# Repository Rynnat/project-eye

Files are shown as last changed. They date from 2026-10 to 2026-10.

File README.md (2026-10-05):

# Project Eye

An animatronic eye mechanism: two eyes that look left/right and up/down, with upper and lower eyelids that blink. Three SG90 micro servos, an Arduino Uno, 3D-printed PLA parts and M3/M4 screws with nuts. Built in a few days as the first module of **Epic Project**, a personal series of human-augmentation builds.

## Built and running

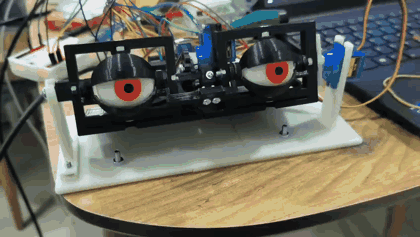
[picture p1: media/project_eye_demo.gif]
Project Eye v5 running on real hardware: eyes look left and right, eyelids move


*v5 on the bench: yaw and eyelids moving (real hardware, 10 s clip).*

## Design

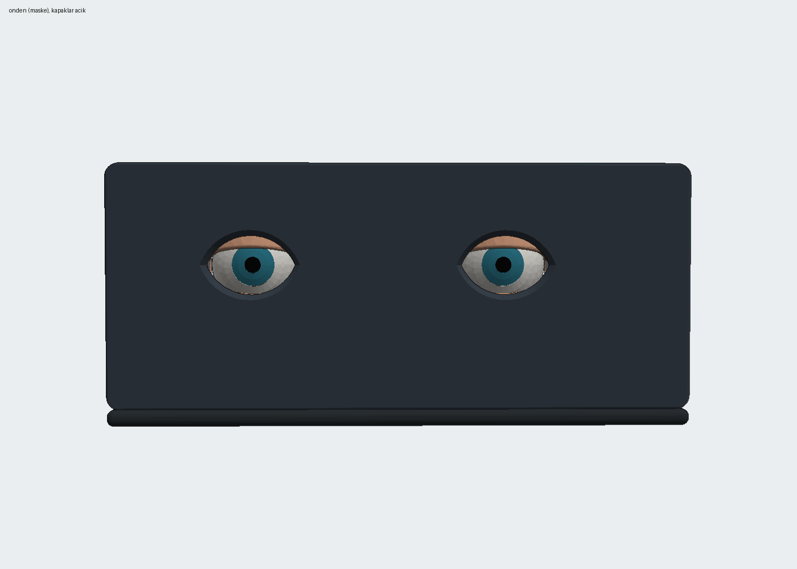
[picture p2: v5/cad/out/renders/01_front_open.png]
Project Eye v5, front view with eyelids open


| Eyelids closed | Three-quarter view | Eyelid drive |
|---|---|---|
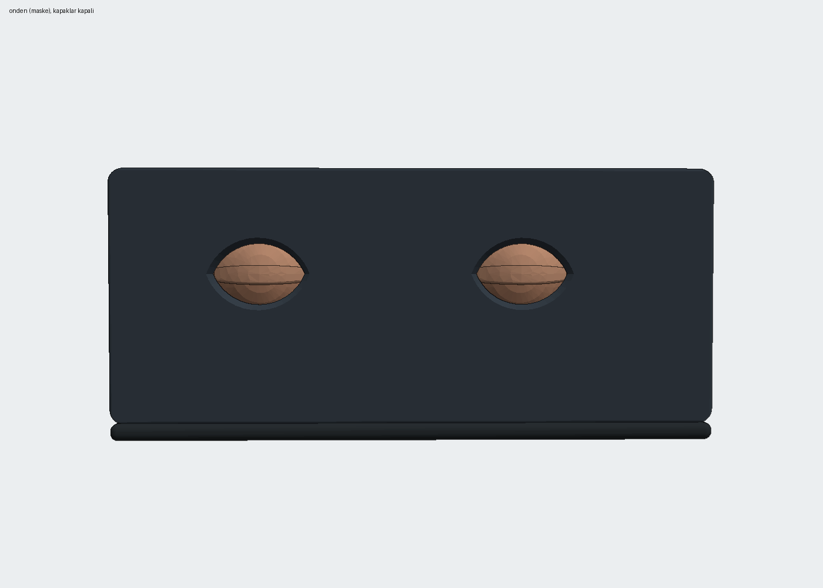
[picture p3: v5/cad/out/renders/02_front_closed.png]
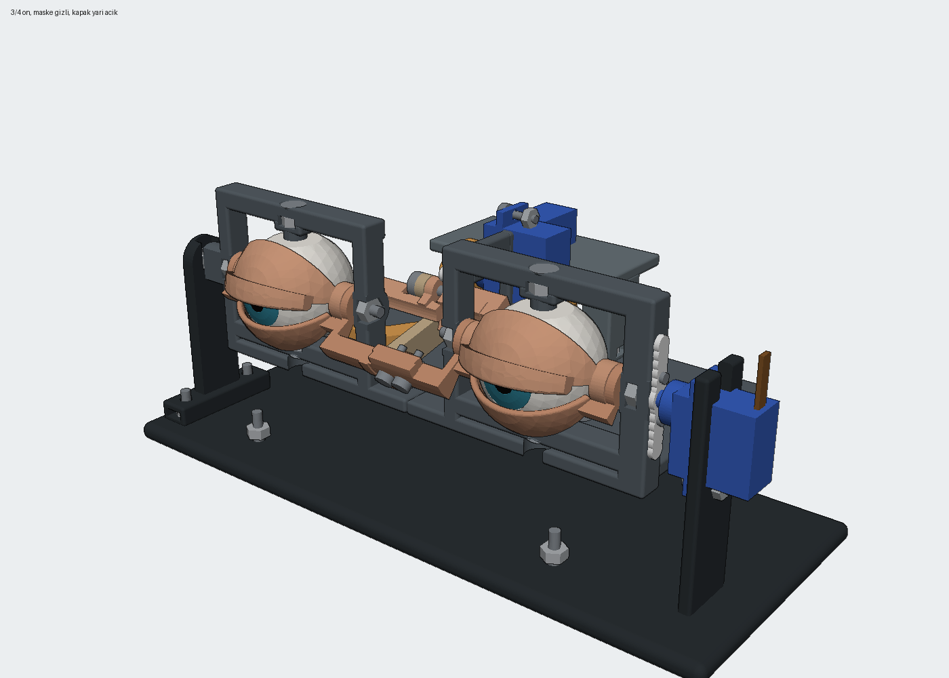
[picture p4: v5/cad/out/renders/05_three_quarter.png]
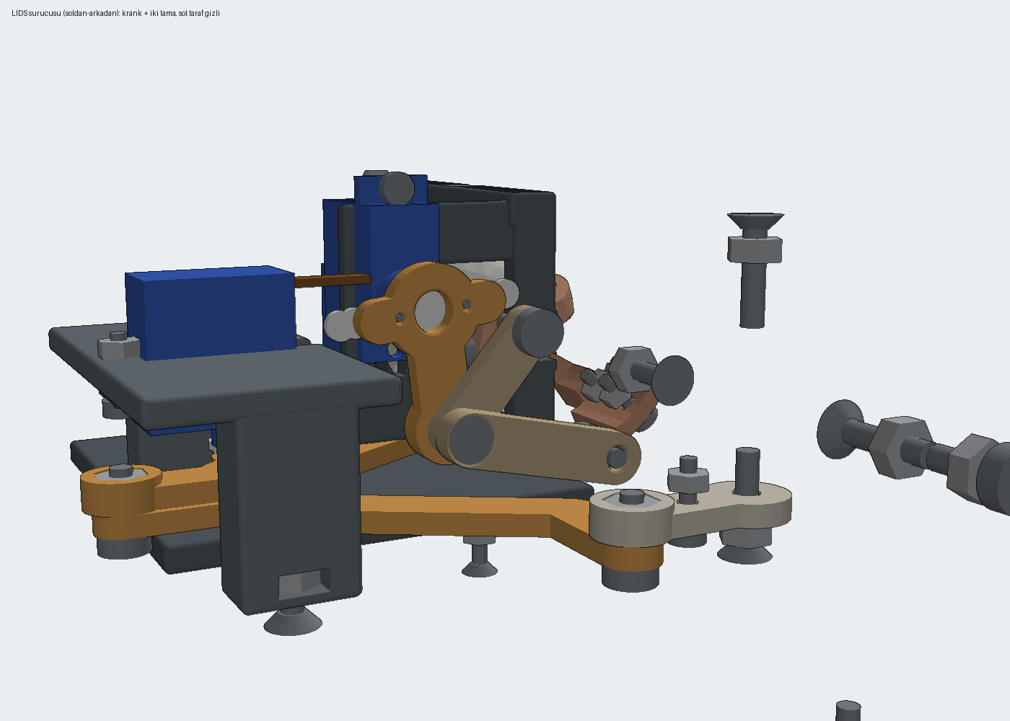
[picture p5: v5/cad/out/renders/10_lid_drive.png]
|  |  |  |

## How it was made

The mechanism was designed as code with AI agents (Claude Code), directed and verified on real hardware by me.

- **CAD as code.** Every part is generated with [CadQuery](https://cadquery.readthedocs.io) from one parameter file (`cad/params.py`). Measured tolerances from printed test pieces go into that file and all parts regenerate.
- **Automatic checks.** After every change the mechanism is swept through 75+ poses (yaw × pitch × eyelid) to check for collisions and minimum clearance (`check.py`). Separate checks catch screws left floating in air (`check_havada.py`) and screws a hand cannot reach in assembly order (`check_montaj.py`). Each of these checks exists because I caught that exact mistake on a printed part.
- **Firmware and control.** Arduino firmware with clamped angle limits taken from the kinematics, a Python serial control library with 45+ unit tests and a simulator, and a button-driven calibration panel.
- **Viewer.** `model.html` is a self-contained 3D viewer of the assembly with live pose sliders.

## Versions

Every version is kept; a revision never edits an older folder.

| Version | What changed |
|---|---|
| v1 | Concept model (viewer only) |
| v2 | Full mechanism: 2 eyes, 4 lids, 6 servos, M2 hardware, ball joints. Software complete, never built |
| v3 | Simplified for a hobby printer: 3 servos, M3/M4 screw pins instead of ball joints |
| v4 | Lower lids on the same servo as the upper lids, front mask, fillets; irises fully covered when closed |
| **v5** | **Built, partly working** (see Status). Captive hex nuts at every joint, separate iris and pupil inserts, base split in two for a 220 mm bed, cable slots on the correct servo end |

## Status

v5 was built as a showcase stand, not as a measured experiment.

- **Yaw (left/right) and eyelids:** work.
- **Pitch (up/down):** the servo moves, but cannot hold the pitch frame under load (the frame also carries the eyelid servo and all four lids). A rubber-band counterbalance on the front of the frame restored free motion, confirming a torque shortfall. A torque check was never part of the design loop; the design notes already flagged it as unverified.
- **Accuracy vs. simulation:** not measured. Since the eyes and lids ride on the pitch frame, their real angles may also differ from the model; hand calibration already found a different yaw range (45–111°) than the model (65–115°).

## v5 at a glance

| | |
|---|---|
| Servos | 3 × SG90: yaw D3, pitch D5, eyelids D6 |
| Board | Arduino Uno, 115200 baud, command `S <yaw> <pitch> <lids>` → `OK` |
| Button | D2 to GND: neutral ↔ idle (LED 13 on in idle) |
| Calibrated range | yaw 45–111° (center 78), eyelids open 80° / closed 115° |
| Parts | 19 STL files, 22 prints, about 250–320 g PLA |
| Hardware | M4×16 countersunk, M4×10 and M3×10 pan head, M3/M4 nuts (see `v5/cad/BOM.md`) |

Folder layout (`v5/`):

```
cad/        params.py, eye_v5.py (geometry), kin.py (kinematics), check*.py, out/ (STL, STEP, GLB, renders)
firmware/   project_eye_v5 (main sketch); notr_yaw_d3, montaj_lids_d3 (assembly helpers)
control/    eye_control.py, sim.py, calibrate.py, kalibrasyon_paneli.py (calibration GUI), face_follow.py, tests/
viewer/     build_viewer.py + template.html → model.html
MONTAJ.md   assembly order (Turkish)
```

## Run it

```powershell
# CAD (Python 3.12 + cadquery)
cd v5/cad
python eye_v5.py; python check.py; python check_havada.py; python check_montaj.py

# Firmware (arduino-cli, board arduino:avr:uno)
arduino-cli compile --fqbn arduino:avr:uno v5/firmware/project_eye_v5
arduino-cli upload  --fqbn arduino:avr:uno -p COM3 v5/firmware/project_eye_v5

# Control (pyserial)
cd v5/control
python -m unittest discover tests
python kalibrasyon_paneli.py --port COM3
```

`face_follow.py` needs mediapipe, OpenCV and a BlazeFace model file; its default path points to my local setup, so pass your own model path.

## Known issues

- **Pitch is weak when looking down.** The parts that tilt with the pitch servo weigh about 225 g, and their center of mass sits about 23 mm behind the pitch axis. Holding it takes about 0.5 kg·cm, roughly 30% of an SG90's stall torque before losses. Fixes: an MG90S (same size, metal gears), a small spring or foam pad under the rear of the frame, and a separate 5 V supply for the servos. Pitch limits (70–110°) are still the model values and have not been calibrated.
- **Servo power.** Running three servos from the Uno's 5 V pin causes brown-out resets on fast moves. Use a separate 5–6 V supply with a shared ground.

## Next

- Face tracking on v5 hardware (`control/face_follow.py`)
- v6: move the center of mass onto the pitch axis

Docs and code comments are partly in Turkish.

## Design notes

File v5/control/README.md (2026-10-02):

# Project Eye v5 — Firmware ve kontrol yazılımı

3 × SG90, Arduino Uno. v3 yazılımının v4 mekaniğine uyarlanmış kopyası (kararlar: `DECISIONS.md`).

> **Durum:** Firmware derleniyor (flash 9538 B %29, RAM 552 B %26); yazılım firmware
> simülatörüne karşı 45 testle doğrulandı. **Gerçek donanımda denenmedi.**

| Kanal | İsim | Pin | Servo aralığı (firmware limiti) |
|---|---|---|---|
| 0 | EYE_YAW | D3 | 65–115 (servo = 90 − yaw) |
| 1 | EYE_PITCH | D5 | 70–110 |
| 2 | LIDS (2 üst + 2 alt kapak) | D6 | 102.29 kapalı … 77.71 açık |

**Kablolama:** servolar **harici 5 V** (≥2 A, 3 A önerilir) kaynaktan; kaynak GND'si **Uno GND'sine
bağlı** (ortak toprak). Harici +5 V'u Uno'ya bağlamayın. Turuncu = sinyal, kırmızı = +5 V,
kahverengi = GND. Servo kolunu takmadan önce servoyu nötre getirin.

## Çalıştırma
```powershell
$py = "C:\Users\LENOVO\epic-project\.venv-ctl\Scripts\python.exe"   # pyserial
cd C:\Users\LENOVO\epic-project\modules\project-eye\v4\control
& $py eye_control.py --sim           # demo (--sim olmadan donanımı arar, yoksa sim)
& $py calibrate.py                   # 1..3 kanal, ok tuşları, c/n/x göz, k/o kapak, s kaydet
& $py -m unittest discover -s tests -v
$env:PYTHONUTF8 = "1"
C:\Users\LENOVO\lunar-tracker\.venv\Scripts\python.exe face_follow.py    # --sim, --port COM5

& "C:\Users\LENOVO\AppData\Local\Programs\Arduino IDE\resources\app\lib\backend\resources\arduino-cli.exe" `
  compile --fqbn arduino:avr:uno ..\firmware\project_eye_v5
```

- Port `auto`: yalnızca açılışta `EYE v5 READY` basan kart kullanılır; Lunar gimbal, v2 ve v3 kartları
  reddedilir. Sabit port için settings.json'da `"serial_port": "COM5"` ya da `EYE_EXCLUDE_PORTS=COM3`.
- `behaviour.lid_follow_pitch` = 0.0: kapaklar pitch'i zaten mekanik olarak izliyor.
- Montajdan sonra: `calibrate.py` ile değerleri bulun; firmware limitlerini yalnızca **daraltın**,
  `IDLE_*` sabitlerini ve `sim.py`'yi yeni settings.json'a çekin (testler farkı yakalar).

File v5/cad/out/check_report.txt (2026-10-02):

PROJECT EYE v5 (v4 + somunlu baglantilar) - MEKANIK KONTROL RAPORU
uretim: check.py | ucgenleme 0.01 mm | kesisim esigi 0.01 mm3 | eklem disi bosluk hedefi 0.4 mm

1) KATI GECERLILIGI
   parca sayisi 96 (basilan 24, farkli basilan STL 19: ['base_L', 'base_R', 'coupler', 'eye', 'eye_lever', 'frame_L', 'frame_R', 'iris', 'lid_lo_L', 'lid_lo_R', 'lid_up_L', 'lid_up_R', 'link_lo', 'link_up', 'mask', 'pivot_bracket', 'pupil', 'yaw_crank', 'yaw_mount'])
   gecersiz kati: yok | tek-kati olmayan basilan: yok | su gecirmez olmayan ag: yok

2) GRUP ICI (birbirine sabit parcalar, notr poz) - kesisim >= esik:
   ! frame_L x scr_ptop_L: 0.012 mm3
   ! frame_L x scr_pbot_L: 0.012 mm3
   ! frame_L x scr_ym_L63: 0.014 mm3
   ! frame_R x scr_ptop_R: 0.012 mm3
   ! frame_R x scr_pbot_R: 0.012 mm3
   ! frame_R x scr_ym_R63: 0.014 mm3
   ! servo_pitch x cable_pitch: 2.340 mm3
   ! servo_pitch x scr_m3_pitch0: 0.434 mm3
   ! servo_pitch x nut_m3_pitch0: 0.776 mm3
   ! servo_yaw x cable_yaw: 2.340 mm3
   ! servo_yaw x scr_m3_yaw0: 0.434 mm3
   ! servo_yaw x nut_m3_yaw0: 0.776 mm3
   ! servo_lid x cable_lid: 2.340 mm3
   ! servo_lid x scr_m3_lid0: 0.434 mm3
   ! servo_lid x nut_m3_lid0: 0.776 mm3
   ! scr_U x lid_up_L: 1.101 mm3
   ! lid_lo_L x lid_lo_R: 2.173 mm3
   ! scr_brk_-4 x base_L: 0.014 mm3
   ! scr_brk_24 x base_L: 0.014 mm3
   ! scr_mask_40 x base_L: 0.014 mm3
   ! scr_mask_160 x base_R: 0.014 mm3
   not: ~0.01-0.02 mm3 = havsa kafa konisi ile yuvasi ayni yuzey (ucgenleme). scr_m3_* x servo_* GERCEK:
        SG90 kulak deligi govdeden ~2.5 mm; M3 kafa (O5.6) govde duvarina biniyor (DECISIONS.md, risk; v3'ten).

3) HAREKET TARAMASI: zorunlu 18 poz (yaw (-25.0, 0.0, 25.0) x pitch (-20.0, 0.0, 20.0) x kapak acik/kapali) + ara tarama 57 poz (yaw 12.5, pitch 10 deg adim, kapak 0/0.5/1)
   ust kapak kenari -4.0 (dudak -10.0) -> +23.0 deg; alt kapak -5.4 -> -34.6 deg
   zorunlu pozlar:  yaw   pitch  kapak  | cakisma | eklem disi min bosluk | en yakin cift
                   -25.0 -20.0  open   |       0 |      0.400 | horn_lid x lid_up_L
                   -25.0   0.0  open   |       0 |      0.400 | coupler x scr_horn_yaw1
                   -25.0  20.0  open   |       0 |      0.400 | coupler x scr_horn_yaw1
                     0.0 -20.0  open   |       0 |      0.400 | horn_lid x lid_up_L
                     0.0   0.0  open   |       0 |      0.400 | horn_lid x lid_up_L
                     0.0  20.0  open   |       0 |      0.400 | horn_lid x lid_up_L
                    25.0 -20.0  open   |       0 |      0.400 | horn_lid x lid_up_L
                    25.0   0.0  open   |       0 |      0.400 | coupler x scr_horn_yaw0
                    25.0  20.0  open   |       0 |      0.400 | coupler x scr_horn_yaw0
                   -25.0 -20.0  closed |       0 |      0.400 | coupler x scr_horn_yaw1
                   -25.0   0.0  closed |       0 |      0.400 | coupler x scr_horn_yaw1
                   -25.0  20.0  closed |       0 |      0.400 | coupler x scr_horn_yaw1
                     0.0 -20.0  closed |       0 |      0.498 | frame_L x lid_up_L
                     0.0   0.0  closed |       0 |      0.498 | frame_L x lid_up_L
                     0.0  20.0  closed |       0 |      0.498 | frame_L x lid_up_L
                    25.0 -20.0  closed |       0 |      0.400 | coupler x scr_horn_yaw0
                    25.0   0.0  closed |       0 |      0.400 | coupler x scr_horn_yaw0
                    25.0  20.0  closed |       0 |      0.400 | coupler x scr_horn_yaw0
   ara tarama: cakisma 0; eklem disi en kucuk bosluk 0.400 mm

   TOPLAM CAKISMA (>= 0.01 mm3): 0
4a) EKLEM DISI CIFTLERDE EN DAR 20 BOSLUK (asil carpisma payi):
     0.400  coupler x scr_horn_yaw0   @ yaw 25.0 pitch 20.0 kapak open
     0.400  coupler x scr_horn_yaw1   @ yaw -25.0 pitch 20.0 kapak open
     0.400  horn_lid x lid_up_L   @ yaw -25.0 pitch -20.0 kapak open
     0.479  eye_lever_R x lid_lo_R   @ yaw 0 pitch -10 kapak 1.0
     0.479  eye_lever_L x lid_lo_L   @ yaw 0.0 pitch 0.0 kapak open
     0.498  frame_L x lid_up_L   @ yaw -25 pitch -10 kapak 0.0
     0.500  scr_ltip_L x frame_L   @ yaw -25 pitch -10 kapak 0.0
     0.500  scr_ltip_R x frame_R   @ yaw -25 pitch -10 kapak 0.0
     0.579  eye_L x lid_up_L   @ yaw 25 pitch -20 kapak 0.5
     0.579  eye_R x lid_up_R   @ yaw 25 pitch -10 kapak 0.5
     0.581  eye_L x lid_lo_L   @ yaw 12.5 pitch -10 kapak 0.0
     0.582  eye_R x lid_lo_R   @ yaw -12.5 pitch -20 kapak 0.0
     0.585  iris_L x lid_up_L   @ yaw -25.0 pitch 0.0 kapak closed
     0.585  iris_R x lid_up_R   @ yaw -25.0 pitch -20.0 kapak closed
     0.585  iris_R x lid_lo_R   @ yaw 25.0 pitch 0.0 kapak closed
     0.585  iris_L x lid_lo_L   @ yaw -25 pitch -10 kapak 0.0
     0.587  pupil_R x lid_lo_R   @ yaw 0 pitch -10 kapak 0.0
     0.587  pupil_L x lid_up_L   @ yaw 0 pitch -10 kapak 0.0
     0.587  pupil_R x lid_up_R   @ yaw 0 pitch -10 kapak 0.0
     0.587  pupil_L x lid_lo_L   @ yaw -12.5 pitch -20 kapak 0.0
4b) EKLEM CIFTLERI (tasarim geregi temas / AXIAL_GAP; en dar 12):
     0.000  scr_ltip_L x coupler
     0.000  scr_ltip_R x coupler
     0.000  servo_pitch x horn_pitch
     0.000  servo_yaw x horn_yaw
     0.000  scr_ctip x coupler
     0.000  servo_lid x horn_lid
     0.000  link_up x scr_U
     0.039  link_lo x scr_A
     0.039  scr_lpin_Ro x lid_up_R
     0.039  scr_lpin_Lo x lid_up_L
     0.039  scr_lpin_Li x lid_up_L
     0.039  scr_lpin_Ri x lid_up_R

5) ET KALINLIGI (isin yontemi; min / %1 / %5, mm) - hedef >= 1.6:
   eye            min  1.60  %1  8.56  %5 14.65  (en ince ~ [-45.3 -11.4 -11.9])
   iris           min  1.97  %1  1.97  %5  1.97  (en ince ~ [-46.2  -2.7  14.1])
   pupil          min  1.65  %1  1.65  %5  1.67  (en ince ~ [-50.1   1.6  17.7])
   eye_lever      min  1.60  %1  1.60  %5  1.60  (en ince ~ [-44.1 -15.3 -21.2])
   frame_L        min  1.25  %1  1.60  %5  4.25  (en ince ~ [-76.    0.    3.5])
   frame_R        min  0.73  %1  1.60  %5  4.05  (en ince ~ [ 18.6  26.5 -29.7])
   yaw_mount      min  0.80  %1  1.60  %5  3.46  (en ince ~ [  0.1   2.6 -77.7])
   yaw_crank      min  1.60  %1  1.60  %5  1.80  (en ince ~ [ -2.7 -15.3 -82.6])
   coupler        min  2.35  %1  2.35  %5  2.36  (en ince ~ [ -2.  -18.1 -80.7])
   link_up        min  1.85  %1  1.85  %5  1.85  (en ince ~ [ -3.9 -10.5 -20.9])
   link_lo        min  2.35  %1  2.35  %5  2.35  (en ince ~ [ -7.6  -8.4 -24.6])
   lid_up_L       min  0.10  %1  1.90  %5  1.99  (en ince ~ [-65.   -1.   11.7])
   lid_lo_L       min  1.60  %1  1.60  %5  1.97  (en ince ~ [ -3.2 -13.1   5.1])
   lid_up_R       min  0.12  %1  1.99  %5  1.99  (en ince ~ [64.9 -0.9 11.7])
   lid_lo_R       min  1.99  %1  1.99  %5  1.99  (en ince ~ [61.3 -6.8 10.5])
   pivot_bracket  min  1.46  %1  1.60  %5  1.60  (en ince ~ [-94.6 -53.9 -19.5])
   base_L         min  2.52  %1  3.00  %5  3.00  (en ince ~ [ -2.4 -54.5 -60.8])
   base_R         min  2.50  %1  3.00  %5  3.00  (en ince ~ [ -9.3 -59.5 -60.9])
   mask           min  1.60  %1  3.00  %5  3.00  (en ince ~ [ 60.8 -52.4   4.1])

6) BASKIDA YATAY DELIKLER (+0.2 mm pay verildi; DECISIONS.md):
   frame_L        ust/alt goz pimi gecisi (Y), 4x kapak mentese gecisi (X), pitch pimi RUN (X, donen)
   frame_R        ust/alt goz pimi gecisi (Y), 4x kapak mentese gecisi (X), 2x pitch kol vidasi (X, servo vidasi), LIDS servo kulagi M3 gecis (X)
   lid_up_L       2x bindirme civatasi (radyal)
   lid_lo_L       2x bindirme civatasi (radyal)
   lid_up_R       2x bindirme civatasi (radyal)
   lid_lo_R       2x bindirme civatasi (radyal)
   pivot_bracket  sol pitch pimi gecisi (X, sabit)
   base_R         2x pitch servo kulagi M3 (X)

7) STL / BASKI YONU KONTROLU (out/stl/*.stl oldugu gibi okunur)
   (1) tek bagli govde  (2) min z = 0, 0.2 mm katmanlarda havada baslayan ada yok  (3) >45 deg sarkma alani
   base_L.stl             govde 1  zmin  0.000  havada ada  0   sarkma  270.7 mm2  tabla 10924.4 mm2  boyut [128.6  89.    6. ]  OK
   base_R.stl             govde 1  zmin  0.000  havada ada  0   sarkma  317.4 mm2  tabla 10909.9 mm2  boyut [128.6  89.   73.5]  OK
   coupler.stl            govde 1  zmin  0.000  havada ada  0   sarkma    0.0 mm2  tabla  1424.6 mm2  boyut [104.   69.    3.5]  OK
   eye.stl                govde 1  zmin  0.000  havada ada  0   sarkma   73.8 mm2  tabla   466.0 mm2  boyut [36.  30.1 29. ]  OK
   eye_lever.stl          govde 1  zmin  0.000  havada ada  0   sarkma    0.0 mm2  tabla   271.2 mm2  boyut [13.  32.4  5. ]  OK
   frame_L.stl            govde 1  zmin  0.000  havada ada  0   sarkma  233.9 mm2  tabla  1498.3 mm2  boyut [88.4 56.5 77.5]  OK
   frame_R.stl            govde 1  zmin  0.000  havada ada  0   sarkma  490.4 mm2  tabla  1578.5 mm2  boyut [83.3 61.5 77.5]  OK
   iris.stl               govde 1  zmin  0.000  havada ada  0   sarkma    0.0 mm2  tabla   201.0 mm2  boyut [16.  16.   3.6]  OK
   lid_lo_L.stl           govde 1  zmin  0.000  havada ada  0   sarkma  412.3 mm2  tabla   112.8 mm2  boyut [26.4 27.6 87.6]  OK
   lid_lo_R.stl           govde 1  zmin  0.000  havada ada  0   sarkma  283.2 mm2  tabla   112.8 mm2  boyut [26.4 20.3 76.4]  OK
   lid_up_L.stl           govde 1  zmin  0.000  havada ada  0   sarkma  433.9 mm2  tabla    98.5 mm2  boyut [39.5 21.1 90.3]  OK
   lid_up_R.stl           govde 1  zmin  0.000  havada ada  0   sarkma  392.7 mm2  tabla    98.5 mm2  boyut [41.  21.1 67.6]  OK
   link_lo.stl            govde 1  zmin  0.000  havada ada  0   sarkma    9.0 mm2  tabla   242.2 mm2  boyut [36.7 15.5  4.5]  OK
   link_up.stl            govde 1  zmin  0.000  havada ada  0   sarkma    0.0 mm2  tabla   182.1 mm2  boyut [19.1 26.1  3.5]  OK
   mask.stl               govde 1  zmin  0.000  havada ada  0   sarkma  367.0 mm2  tabla 18367.7 mm2  boyut [217.5  92.   30.4]  OK
   pivot_bracket.stl      govde 1  zmin  0.000  havada ada  0   sarkma  110.3 mm2  tabla   379.7 mm2  boyut [11. 40. 62.]  OK
   pupil.stl              govde 1  zmin  0.000  havada ada  0   sarkma    0.0 mm2  tabla    28.3 mm2  boyut [6.  6.  1.9]  OK
   yaw_crank.stl          govde 1  zmin  0.000  havada ada  0   sarkma    0.0 mm2  tabla   366.7 mm2  boyut [26.  33.9  5. ]  OK
   yaw_mount.stl          govde 1  zmin  0.000  havada ada  0   sarkma   97.4 mm2  tabla  2063.3 mm2  boyut [69.  35.4 30.4]  OK
   STL SONUC: hepsi OK

8) VIDA SAYILARI (montaj kaydindan):
     8  M3 somun
     8  M3x10 yuvarlak
    20  M4 somun
     6  M4x10 yuvarlak
    15  M4x16 havsa
     3  SG90
     3  SG90 kablo cikisi
     6  SG90 kol vidasi (servo ile gelir)
     3  SG90 kolu (cift)
   M3 toplam 8 (sinir 14) -> OK
8b) VIDA BOYU / SOMUN KONTROLU: vida ucu somunun dis yuzunden en az 1 dis (M3 0.5, M4 0.7) cikmali;
    vidalarin/somunlarin baska parcaya carpmamasi bolum 2-4'teki carpisma taramasinda (vida ve somun katilari dahil).
   scr_lock_L       + nut_lock_L       M3: uc somundan  2.10 mm tasar  OK
   scr_ltip_L       + nut_ltip_L       M4: uc somundan  1.30 mm tasar  OK
   scr_lock_R       + nut_lock_R       M3: uc somundan  2.10 mm tasar  OK
   scr_ltip_R       + nut_ltip_R       M4: uc somundan  1.30 mm tasar  OK
   scr_ptop_L       + nut_ptop_L       M4: uc somundan  9.45 mm tasar  OK
   scr_pbot_L       + nut_pbot_L       M4: uc somundan 10.50 mm tasar  OK
   scr_lpin_Lo      + nut_lpin_Lo      M4: uc somundan  3.30 mm tasar  OK
   scr_lpin_Li      + nut_lpin_Li      M4: uc somundan  3.30 mm tasar  OK
   scr_ptop_R       + nut_ptop_R       M4: uc somundan  9.45 mm tasar  OK
   scr_pbot_R       + nut_pbot_R       M4: uc somundan 10.50 mm tasar  OK
   scr_lpin_Ro      + nut_lpin_Ro      M4: uc somundan  3.30 mm tasar  OK
   scr_lpin_Ri      + nut_lpin_Ri      M4: uc somundan  3.30 mm tasar  OK
   scr_fpivot       + nut_fpivot       M4: uc somundan  5.20 mm tasar  OK
   scr_m3_yaw0      + nut_m3_yaw0      M3: uc somundan  1.10 mm tasar  OK
   scr_ym_L63       + nut_ym_L63       M4: uc somundan  6.90 mm tasar  OK
   scr_ym_R63       + nut_ym_R63       M4: uc somundan  6.90 mm tasar  OK
   scr_ctip         + nut_ctip         M4: uc somundan  1.30 mm tasar  OK
   scr_m3_lid0      + nut_m3_lid0      M3: uc somundan  1.00 mm tasar  OK
   scr_A            + nut_A            M4: uc somundan  2.64 mm tasar  OK
   scr_L            + nut_L            M4: uc somundan  5.20 mm tasar  OK
   scr_lap_up0      + nut_lap_up0      M3: uc somundan  1.60 mm tasar  OK
   scr_lap_lo0      + nut_lap_lo0      M3: uc somundan  2.60 mm tasar  OK
   scr_lap_lo1      + nut_lap_lo1      M3: uc somundan  2.60 mm tasar  OK
   scr_brk_-4       + nut_brk_-4       M4: uc somundan  5.50 mm tasar  OK
   scr_brk_24       + nut_brk_24       M4: uc somundan  5.50 mm tasar  OK
   scr_mask_40      + nut_mask_40      M4: uc somundan  5.50 mm tasar  OK
   scr_mask_160     + nut_mask_160     M4: uc somundan  5.50 mm tasar  OK
   scr_m3_pitch0    + nut_m3_pitch0    M3: uc somundan  1.10 mm tasar  OK
   somunlu baglanti 28, kisa vida: yok
   KILAVUZSUZ (plastige vidalanan) kalan: ['scr_U'] (M4, ust kapak tabi; bkz. DECISIONS) + SG90 kol vidalari (servo ile gelen)

9) SERVO ACILARI (derece) + kapak acilari:
   kapak 0.00: ust + 0.00 deg, alt - 0.00 deg, krank   0.00 deg, LIDS 102.29; lama iletim sapmasi (0 ideal) ust  6.1 alt 31.0 krank-ust 38.9 krank-alt 32.7
   kapak 0.25: ust + 6.75 deg, alt - 7.59 deg, krank  -6.40 deg, LIDS  95.89; lama iletim sapmasi (0 ideal) ust  4.5 alt 23.2 krank-ust 41.4 krank-alt 26.1
   kapak 0.50: ust +13.50 deg, alt -15.29 deg, krank -12.90 deg, LIDS  89.39; lama iletim sapmasi (0 ideal) ust 16.2 alt 15.3 krank-ust 43.0 krank-alt 19.3
   kapak 0.75: ust +20.25 deg, alt -22.66 deg, krank -19.10 deg, LIDS  83.18; lama iletim sapmasi (0 ideal) ust 28.7 alt  7.5 krank-ust 43.4 krank-alt 12.8
   kapak 1.00: ust +27.00 deg, alt -29.22 deg, krank -24.58 deg, LIDS  77.71; lama iletim sapmasi (0 ideal) ust 41.7 alt  0.6 krank-ust 42.7 krank-alt  6.9
   yaw    0 pitch    0 kapak closed: EYE_YAW   90.0  EYE_PITCH   90.0  LIDS  102.3
   yaw  -25 pitch    0 kapak closed: EYE_YAW  115.0  EYE_PITCH   90.0  LIDS  102.3
   yaw   25 pitch    0 kapak closed: EYE_YAW   65.0  EYE_PITCH   90.0  LIDS  102.3
   yaw    0 pitch  -20 kapak closed: EYE_YAW   90.0  EYE_PITCH   70.0  LIDS  102.3
   yaw    0 pitch   20 kapak closed: EYE_YAW   90.0  EYE_PITCH  110.0  LIDS  102.3
   yaw    0 pitch    0 kapak open  : EYE_YAW   90.0  EYE_PITCH   90.0  LIDS   77.7
   yaw    0 pitch    0 kapak 0.25  : EYE_YAW   90.0  EYE_PITCH   90.0  LIDS   95.9
   yaw    0 pitch    0 kapak 0.5   : EYE_YAW   90.0  EYE_PITCH   90.0  LIDS   89.4
   yaw    0 pitch    0 kapak 0.75  : EYE_YAW   90.0  EYE_PITCH   90.0  LIDS   83.2

9b) KAPAK - GOZ BOSLUGU (kapak ic yuzu - goz, butun pozlar): en kucuk 0.579 mm (eye_L x lid_up_L), hedef <= 1.0 ve >= 0.4  (tasarim: LID_R_IN - EYE_R = 0.60)
    0.579  eye_L x lid_up_L
    0.579  eye_R x lid_up_R
    0.581  eye_L x lid_lo_L
    0.582  eye_R x lid_lo_R

10) KAPALI POZDA IRIS + BEBEK GORUNUR ALANI (onden z-tamponu, 0.1 mm piksel; hedef 0)
   maske ile                    bakis (yaw  +0, pitch  +0): 9 goz pozunda en cok 0.00 mm2
   maske ile                    bakis (yaw +15, pitch  +0): 9 goz pozunda en cok 0.00 mm2
   maske ile                    bakis (yaw -15, pitch  +0): 9 goz pozunda en cok 0.00 mm2
   maske ile                    bakis (yaw  +0, pitch +12): 9 goz pozunda en cok 0.00 mm2
   maske ile                    bakis (yaw  +0, pitch -12): 9 goz pozunda en cok 0.00 mm2
   maske YOK (yalniz kapaklar)  bakis (yaw  +0, pitch  +0): 9 goz pozunda en cok 0.00 mm2
   maske YOK (yalniz kapaklar)  bakis (yaw +15, pitch  +0): 9 goz pozunda en cok 0.00 mm2
   maske YOK (yalniz kapaklar)  bakis (yaw -15, pitch  +0): 9 goz pozunda en cok 0.00 mm2
   maske YOK (yalniz kapaklar)  bakis (yaw  +0, pitch +12): 9 goz pozunda en cok 0.00 mm2
   maske YOK (yalniz kapaklar)  bakis (yaw  +0, pitch -12): 9 goz pozunda en cok 0.00 mm2
   (karsilastirma: kapak ACIK, maskesiz, notr: 190 + 190 mm2 gorunur)
   kapak ACIK, notr, onden: gorunen iris ust siniri y = 6.40 (iris tepesi +8) -> ust kapak irisin 1.60 mm'sini orter; alt sinir y = -7.90 (iris dibi -8; alt kapak irisin altinda)
   IRIS SONUC: kapali pozda en cok 0.00 mm2 gorunur

SONUC: cakisma 0, eklem disi en kucuk bosluk 0.400 mm (coupler x scr_horn_yaw0 @ (25.0, 20.0, 'open')), gecersiz kati 0, 1.6 alti et (%1) yok, STL hatasi yok, M3 8/14, farkli STL 19/19, kapak-goz 0.58 mm, kapali iris 0.00 mm2, somunlu 28 (kisa vida 0)
sure 332 s

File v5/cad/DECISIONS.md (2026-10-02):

# Project Eye v5 — somunlu bağlantılar (v4 + M3/M4 somun)

**v5 nedir:** v4 (`../../v4/`) olduğu gibi duruyor. Kullanıcının elinde M3 ve M4 **somunlar** da var. v5, v4'ün aynı mekanizması;
plastiğe kılavuzsuz vidalama (`M3_PILOT`/`M4_PILOT`) nerdeyse tamamen kalktı, yerine **gömülü (captive) altıgen somun cepleri** geldi.
Kinematik ve servo aralıkları v4 ile **birebir aynı** (`out/kinematics.json` → settings_suggestion ve LIDS tablosu v4 ile eşit; kontrol edildi).
Aşağıdaki §0 v5'e özgü; §1 ve sonrası v4 kararlarıdır (sayılar v5'e göre güncellendi).

## 0. Somun tasarımı [SEÇİM]
- Ölçü (ISO 4032): M3 AF 5.5 × 2.4, M4 AF 7.0 × 3.2. Cep: AF + `NUT_POCKET_CLR` 0.3, derinlik + `NUT_POCKET_DEPTH_CLR` 0.2 (`params.py §1`, [TOL]).
- **Cep kuralı:** somunun vida kafası tarafındaki yüzü plastiğe dayanır (yük oraya biner); cep uç tarafa ya da bir yüzeye açıktır.
  Kaydırmalı cepte kanal duvarları somunun iki düz yüzüne paraleldir → somun dönmez.
- **Baskı:** (a) cep ekseni baskıda dikeyse (göz kolu ucu, krank ucu, kapak tabı, göz, taban/maske ayakları) üstten ya da yandan açık düz altıgen;
  (b) kafeslerde (ön yüzü tablada basılır) eksen yatay → cep **ön yüze (tablaya) açık kanal**, tavanı altıgenin 60° köşesi → destek yok;
  (c) pivot_bracket'ta kanal yukarı açık.
- **Vida boyu kontrolü** (`check.py §8b`): 29 somunlu bağlantının hepsinde vida ucu somunun dış yüzünden ≥ 1 diş (M3 0.5, M4 0.7) çıkıyor
  (en az: bindirme M3 0.7, LIDS kulak M3 1.0, göz kolu ucu M4 1.3). Vidalar ve somunlar çarpışma taramasında katı olarak var → hiçbiri başka parçaya değmiyor.

| Bağlantı | Vida | Somun nerede | Tür |
|---|---|---|---|
| Göz üst pimi ×2 | M4×16 havşa (üst köprü, üstten) | köprü altındaki blokta, öne açık kanal | kafa+somun köprüyü sıkar, göz uçta döner |
| Göz alt pimi ×2 | M4×16 havşa (alttan) | alt köprünün üst yüzünde (kol altında), öne açık | aynı |
| Kapak menteşesi ×4 | **M4×16 havşa** (v4: M4×10), kafa üst kapak göbeğinin havşasında | kafes plakasında, öne açık kanal | kapaklar kafa ile plaka arasında döner |
| Pitch pimi (sol) | M4×10 | **pivot_bracket'ta** (üstten kanal) — vida artık yatağa kilitli, çerçeve göbeği RUN'da döner | kilitli |
| Göz kolu ucu ×2, yaw krank ucu | M4×10 (lamanın altından) | kolun / krankın uç göbeğinde, üstten açık | lama kafa ile parça arasında döner |
| LIDS krank ucu (A) | M4×16 havşa | krank uç göbeği (yaw_crank ile aynı STL) | lamalar arada döner |
| Alt kapak pimi (L) | M4×10 | alt kapak tabının göbeğinde (lama tarafına açık) | lama uçta döner |
| Göz kolu kilidi ×2 | M3×10 | **gözün içinde**, arka düzden kaydırmalı | sabit |
| Orta bindirmeler (4) | M3×10 radyal (v4: M4/M3 karışık) | sol parçanın iç katında, eksen tarafına açık | sabit |
| yaw_mount ↔ kiriş ×2 | M4×16 havşa (alttan) | bacakta, dışa açık kanal (v4: bacak başına 2 → 1) | sabit |
| Servo kulakları ×3 | M3×10 | tutucu plakanın arkasında serbest somun | sabit |
| pivot_bracket, maske ↔ base (2+2) | M4×16 havşa (alttan) | ayak / ped içinde, yandan / arkadan kanal | sabit |

- **Kalan kılavuzsuz delikler:** (1) **üst kapak lama pimi (scr_U, M4×10)** — tab 3.1 mm ince, bir yanında LIDS servo kolu (0.4 mm boşluk), öbür yanında üst lama; somun cebi ya da dışarıda somun sığmıyor. (2) SG90'ın kendi küçük kol vidaları (servoyla gelen sac vidaları, M3/M4 değil).
- **Menteşelerde gevşeme [DOĞRULANMADI]:** göz pimlerinde ve pitch piminde sabit parça kafa ile somun arasında sıkışır → vida kilitli. Kapak menteşesi, lama pimleri ve krank uçlarında ise dönen parça kafa ile somun arasında; vida sıkılırsa eklem kilitlenir. "Serbest dönene kadar geri al" gerekir. Düz somun + dönme titreşimi vidayı gevşetebilir → bu eklemlerde bir damla vida sabitleyici / oje, ya da varsa nyloc önerilir.

### v5'te düzeltilen v4 hataları (v4'e dokunulmadı; v4 kullanılacaksa bilinmeli)
1. **Göz kolu kilit vidası gözün dışına düşüyordu:** v4'te M3 pilotu z −10.2'de, gözün arka düzü z −10 → deliğin çoğu göz dışında. v5: arka düz z −14, kilit z −10.5, M3 somun gözün içinde.
2. **Alt göz pimi vidası takılamıyordu:** arka kiriş alt köprünün 1.1 mm altından geçiyor, 16 mm vidanın alttan girmesine yer yok. v5: kirişte her gözün altında Ø9.6 erişim deliği.

### v5 ölçü değişiklikleri
Üst köprü y 21.2…27.5 (+ somun bloğu y 18.7…), köprüler z −6'ya kadar, sağ dış plaka 8.6 mm (menteşe vidası ucu), sol dış göbek x_rel 41'e kadar,
pivot_bracket 5.0 mm, pitch servosu 3 mm dışarıda (mil x 84.9; açı ilişkisi aynı), base/maske x −101…+116.5 (**217.5 mm**, tabla 220'ye sığıyor ama sınırda),
yaw_mount bacakları x 23.5–34.5, göz kolu alt yüzü tablada basılır (uç göbeği yukarı).

# (v4 kararları) Project Eye v4 — mekanik kararlar (v3 POC'nin revizyonu)

> v5 notu: aşağıdaki metin v4'ten. Vida türü/boyu ve "pilot" geçen yerler §0 ile değişti (somunlu); güncel sayılar §0, `BOM.md` ve `out/check_report.txt`.

**v4 nedir:** v3 (`../../v3/`) olduğu gibi duruyor; bu klasör onun mekanik revizyonu. Şartname v3 SPEC.md + revizyon isteği:
(1) alt kapaklar geri, aynı LIDS servosunda, kapalıyken iris+bebek tamamen örtülü; (2) kapak–göz boşluğu ≤ 1.0 mm;
(3) ön maske; (4) yuvarlatılmış kenarlar, düzenli yerleşim; (5) ≤ 16 farklı STL, M3 ≤ 14. Malzeme kısıtları v3 ile aynı
(M4×10 yuvarlak, M4×16 havşa, M3×10 ≤ 14; M2/somun/pim/rotil/tel yok; her dönen eklem M4 vida = pim).
Servo ölçüsü kullanıcı ölçümüyle güncel (`SG_L 22.5`, `SG_W 12.5`, cep boyu +0.4, eni +0.2 — `params.py §1, §8`).

Etiketler: **[SEÇİM]** tasarım kararı · **[SAPMA]** istekten/v3'ten ayrılma · **[DOĞRULANMADI]** yalnız model/hesap.
Sayılar `params.py`'de. Doğrulama: `out/check_report.txt`. Değişince: `python eye_v5.py && python check.py && python render.py`.

## 1. Mimari (v3'ten farkı)

| | v3 | v4 |
|---|---|---|
| Göz tutucu | çerçeve kolu gözle kapak arasından geçiyordu (kapak göze 3.3 mm) | **kafes**: her gözün iki yanında dikey plaka + üstte/altta köprü. Hiçbir çerçeve parçası kapak kabuğunun (R 18.6–20.6) bandına girmez |
| Kapaklar | 2 üst kapak, sabit gövdede, R 21.3 | **4 kapak (2 üst + 2 alt), çerçevede**, küre kabuk dilimi R 18.6–20.6 → **gözden 0.6 mm** |
| Kapak mafsalı | taşıyıcı servo milinde | her gözün **iki yanında** (4 kutup) M4×10: vida kafası üst kapak göbeğinin cebinde, gövdesi alt kapak göbeğinden geçip kafes plakasına vidalı |
| LIDS | servo mili = kapak ekseni (direkt) | servo **çerçevede** (sağ gözün arkası), krankı (= yaw_crank ile aynı STL) ucundaki tek pime iki lama: üst lama ≈ paralelkenar (üst kapaklar), alt lama **çapraz** (alt kapaklar ters yönde) |
| Maske | yok | ön maske, badem açıklıklar (arkadan öne genişleyen pah) |
| Parça | 12 STL | 16 STL (sınır) |

- **Kapaklar pitch'i mekanik olarak izler [SEÇİM]:** kapaklar pitch çerçevesinde. Göz aşağı bakınca kapaklar da iner (doğal göz kapağı). Asıl neden: kapakları sabit gövdeye koyarsak pitch ±20'de dönen çerçeve (üst/alt pim göbekleri) kapak bandını keser. Sonuç: yazılımdaki `lid_follow_pitch` artık mekanik takibin ÜSTÜNE eklenir → v4'te 0'a yakın başlayın (kinematics.json → cross_coupling).
- **Göz = küre, kapak = eş merkezli küre kabuk:** göz hangi pozda olursa olsun kapak iç yüzü ile göz arası 0.6 mm sabit (check §9b: 0.579 ölçüldü; ~0.02 üçgenleme).
- **Kapalıyken örtme:** üst kapak kenarı −4°, alt kapak kenarı −5.4° (arada 1.4° ≈ 0.45 mm). Aradaki çizgiyi üst kapağın **dudağı** (R 21–23, −10°'ye iner, |x_rel| ≤ 17.5, ucu R1 tam yuvarlak) önden kapatır; dudak alt kapağın 0.4 mm önünden geçer. check §10: 9 göz pozu × 5 bakış açısı (±15° yaw, ±12° pitch eğik bakış dahil), maskeli ve maskesiz: **görünen iris+bebek = 0.00 mm²**.
- **Açıkken:** üst kapak +27° (dudak kenarı +17°) → irisin üst **1.60 mm**'sini örter (check §10, önden z-tamponu); alt kapak −29.2° (kenar −34.6°) → irisin altında.
- **Göz arkadan takılır:** gözün arkasında (x_rel ±18, y −13…16) kafes parçası yok; üst köprü göbeği y 16.4'te (göz üst düzlemi y 16). Kapak mafsal vidaları gözün tarafından takıldığı için **kapaklar gözden ÖNCE** takılır (BOM §4).

### LIDS dört-çubuk [SEÇİM]
YZ düzleminde (çerçeve koordinatı): servo mili S = (y 9.6, z −29.3), krank r = 20 (yaw_crank STL'i), krank ucu kapalıda φ −70.4°.
Üst pim U (ρ 14.5, φ 142.4), alt pim L (ρ 16.5, φ −72.1); lama boyları 21.2 / 28.4. Rastgele tarama (~60 bin aday) + geometrik kısıtlar
(lamalar üst çubuktan, yaw lamasından, yaw servosundan, maskeden uzak; tek yönlü/monoton; |krank| ≤ 40°) ile seçildi.
- Üst kapak 0 → 27°, alt kapak 0 → 29.2° (hafif doğrusal değil), krank 0 → −24.6°.
- İletim sapması (0 = ideal 90°): en kötü ~43° (krank–üst lama), yani iletim açısı ≥ ~47°. Kapaklar hafif; SG90 için yeterli sanılıyor **[DOĞRULANMADI]**.
- **LIDS servo aralığı DEĞİŞTİ:** kapalı **102.3°**, açık **77.7°** (v3: 112.5 / 67.5). Kontrol yazılımı `kinematics.json → channels.LIDS.table` (11 satır, lid 0..1) ve `settings_suggestion` ile güncellenmeli.
- Sol ve sağ kapak parçaları ortada **bindirmeli** (sol parça iç kat, sağ parça dış kat) radyal civatayla birleşir: üstte M4×10 + M3×10, altta 2× M4×10.

### Yaw paralelkenarı
v3 ile aynı (kollar r 20, düz lama, yaw = servo açısı). Değişenler: yaw servosu z −60'a alındı (LIDS krankına yer), lama ortada geriye kıvrık (LIDS alt laması önünden geçer); göz kolu kilidi artık **M3×10, pimin arkasında** (önde alt kapak var).

## 2. Sapmalar / sınırlar [SAPMA]
1. **Parça sayısı tam 16** (sınırda). LIDS krankı yaw_crank ile aynı STL olduğu için sığdı.
2. **Maske asimetrik:** x −98.5…+113.5 (212 mm, tabla 220). Sağdaki pitch servosu gövdesi x 111'e uzanıyor; simetrik maske 226 mm olurdu. Gözler maskenin ortasından 7.5 mm sola kayık.
3. **Kablo yarığı ↔ kulak vidası:** SG90'ın kablo ucundaki kulak deliği, korunması istenen kablo yarığının tam üstüne düşüyor (v3'te de aynı: o delikte plastik yok). v4'te her servo **tek M3** (mil tarafı kulak) + cep ile tutuluyor; kablo tarafı kulağa vida konmadı. Gerekirse o kulağa sıcak tutkal.
4. **Eğik bakışta maskenin arkası:** önden (±15°) yalnız göz ve kapaklar görünür; çok yandan (render 04) badem köşelerinden kafes plakası görülebilir.
5. **Kapak ucunda ince kenar:** dudak |x_rel| 17.5'te düz kesik; iç yüzle 34°'lik kama (min 0.1 mm, %1 1.6 mm). Maske arkasında, işlevsel değil.
6. Göz kolu kilit vidası M3 (v3'te M4×16 havşa) — alttan erişim alt köprüden geçemiyordu.

## 3. Baskı yönü ve kurallar
- **Dikey delik kuralı:** göz, göz kolu, lamalar, kranklar, yaw_mount delikleri baskıda dikey; tabladaki ağızlarda `BOTTOM_CHAMFER` 0.4 pah.
- **Kafesler (frame_L/R) ÖN YÜZÜ (z = +3.5) tablada:** plakalar, köprüler, kiriş z yönünde prizmatik → desteksiz. Yatay kalan delikler (+0.2 pay, `HORIZ_HOLE_EXTRA`): üst/alt göz pimi pilotları (Y), 4 kapak menteşe pilotu (X), sol pitch pimi pilotu, sağda pitch kolu vidaları ve LIDS servo kulağı M3. Pilotlar (vida sabit) → risk düşük. LIDS kanadının alt kenarı ~28 mm köprü (iki ucu dayalı) — hafif sarkabilir.
- **Kapaklar X ekseni dik** (dış göbek yüzü tablada): kutup çevresindeki kubbe ve dudak altı sarkma (check §7: 290–460 mm²) → **bu dört parçada destek (tree/normal) önerilir**; havada başlayan ada yok.
- **Maske ön yüzü tablada**, ayak ve cıvata pedleri dik duvar. Base: taban tablada.
- STL kontrolü (check §7): 16 STL'nin hepsi tek gövde, z_min = 0, 0.2 mm katmanlarda havada başlayan ada yok.

## 4. Kalite / estetik
- Görünen dış kenarlar: kutu parçalar `rbox` ile R1.0 yuvarlatılmış (kafes, köprüler, kiriş, yaw_mount, base R3, maske dış köşeler R6 + R1.2); alt kapak üst kenarı R0.9 fileto; üst kapak dudağı R1.0 tam yuvarlak; maske açıklıkları arkadan öne 2 mm genişleyen pah.
- Servolar: pitch sağ dışta (v3 gibi), yaw ve LIDS gözlerin arkasında toplu; önden bakınca maske hepsini gizler.
- Render: `out/renders/01–11` (önden açık/kapalı/bakış, 3/4 maskeli ve maskesiz, göz yakın açık/kapalı, arka 3/4, yan, LIDS sürücüsü, alt).

## 5. Doğrulama özeti (`out/check_report.txt`, son çalıştırma)
- 18 zorunlu + 57 ara poz (kapak 0 / 0.5 / 1): **çakışma 0**.
- **Eklem dışı en küçük boşluk 0.400 mm** (v5; yaw lama ↔ servo kol vidası ve LIDS kolu ↔ üst kapak tabı). v4'teki 0.398 (kafes plakası ↔ üst kapak çubuğu) v5'te 0.498.
- **Kapak–göz 0.58 mm** (tasarım 0.60; hedef 0.4–1.0).
- **Kapalı pozda görünen iris+bebek 0.00 mm²** (maskeli ve maskesiz, eğik bakışlar dahil).
- Et kalınlığı %1 ≥ 1.6 bütün parçalarda. Tek-katı, geçerli katı, su geçirmez ağ: hepsi OK.
- Vida (v5): M3×10 9/14, M4×10 6, M4×16 havşa 15; somun M3 9, M4 20.
- **Yöntem sınırları:** rijit, boşluksuz model; baskı toleransı, sürtünme, esneme, servo torku **[DOĞRULANMADI]**.

## 6. Riskler
1. **Kapak menteşesi:** M4×10 kafası üst kapak göbeğindeki cepte döner (kafa altı = eksenel yatak). Vida plakada pilotta sabit; çok sıkılırsa kapaklar sıkışır → "serbest dönene kadar geri al". Eksenel oynama kapakları 0.4 mm kaydırabilir; göz boşluğu 0.6 **[DOĞRULANMADI]**.
2. **Dört-çubuk iletim açısı ~47°** (en kötü uç) — sürtünmeyle SG90 zorlanabilir; kapaklar hafif olduğu için sorun beklenmiyor **[DOĞRULANMADI]**.
3. **Pitch servosu artık daha ağır bir çerçeve taşıyor** (+ LIDS servosu + 4 kapak). Ağırlık merkezi eksenin gerisinde; tork hesabı YAPILMADI **[DOĞRULANMADI]**.
4. **Sağ dış plakada pitch kolunun merkez vidası yok:** plaka merkezinde kapak menteşe vidasının pilotu var. Kol, 2 küçük vida + çerçevenin sol pim ile eksenel sıkıştırılmasıyla milde kalır.
5. İnce et: SG90 kulak deliği ↔ servo cebi arası ~1.0–1.1 mm (LIDS kanadı, yaw_mount) — SG90 geometrisi, v3'te de vardı.
6. Kafeslerin iki yarısı yalnız yaw_mount (4× M4×16) ile birleşiyor; ortada kiriş yüzleri temas eder.
7. `lid_follow_pitch` yazılım ayarı mekanik takiple üst üste biner (bkz. §1).
8. Kapak parçaları desteğe muhtaç (bkz. §3); uzun (~90 mm) ince çubuklu baskı → brim önerilir.

## 7. Dosyalar
`params.py` ölçüler · `kin.py` kinematik (yaw/pitch kapalı formül + LIDS dört-çubuk çözücü) · `eye_v5.py` parçalar + montaj +
`build()`, `pose_transforms(yaw, pitch, lid)`, `servo_angles()`, `tess()` (v3 API'si; yeni gruplar: `lids` = üst kapaklar, `lids_lo`,
`lidcrank`, `link_up`, `link_lo`; GLB düğümleri `G_<grup>`) · `kinematics_export.py` → `out/kinematics.json` (v3 formatı; LIDS tablosu
11 satır + üst/alt kenar açıları) · `check.py` → `out/check_report.txt` (yeni: §9b kapak–göz, §10 iris görünürlüğü) · `render.py` → `out/renders/`.
Not: v3'ün görüntüleyicisi (`v3/viewer`) grupları `pose_transforms`'tan genel olarak okur; v4 için henüz model.html üretilmedi.

## 2026-09-29 kullanici geri bildirimleri
- Servo kolu delikleri r=6 (kullanicinin cift kolu olculdu; capraz kolda 5). Kol ucu yaricapi <=16.5 guvenli, 17.5'te LIDS kolu yaw_mount'a carpar -> uzun kol kesilir.
- Iris + bebek ayri basilir (tek renk baskida beyaz top olmasin): gozde O16.2 x 2 cep, iris O16 (on yuzu goz kuresi), ortasinda O6.15 x 1.9 bebek cebi. Paylar [TOL], gevsekse yapistirici.
- Kablo yarigi MILE YAKIN uca tasindi (kullanici gercek serVoda gordu; v3/v4'te uzak uctaydi). Kablo cikisi (cable_*) carpisma taramasina eklendi. Degisen STL: base, frame_R, yaw_mount (+ eye, iris, pupil).
- Kulak vidasi (M3 + somun, her servoda 1) MILE UZAK kulaga tasindi: yeni kablo yarigi mile yakin kulaktaki vidayi kesiyordu (olculdu, 0 mm). STL degismedi (iki kulak deligi zaten acik), yalniz montaj/goruntuleyici. Yarik-vida mesafesi artik > 2.5 mm.
- Kapak servosu kanadi LS_WING_Y 26 -> 32.5: kulak vidasi uzak kulaga tasininca havada kalmisti (kullanici buldu). check_havada.py eklendi (vida/somun en yakin basili parcaya <= 0.6 mm). Degisen: frame_R.
- Taban iki parca (kullanici, 2026-09-30): ortadan, 40 mm yatay bindirme; alt dil (3 mm) servolu base_R'ye, ust dil base_L'ye; yalniz yapistirma, dil ucu boslugu 0.2. base_L ters basilir (PR_YDOWN). Toplam hacim 117.28 (eski 117.38, fark = dil bosluklari).
- MONTAJ ERISIMI (kullanici 2026-09-30: "vida oraya isinlanmayacak"): check_montaj.py eklendi (her vidanin giris koridoru: kafa x vida boyu + 30 mm uc, MONTAJ SIRASINA gore; hepsi-takili modu --takili). Basilmis parcalar DONDURULDU (eye_lever, link_up, link_lo, yaw_crank, pivot_bracket, coupler, yaw_mount, frame_L, frame_R: md5 ayni). Cozumler: (1) scr_U: lid_up_L kolunda kafa+tornavida kanali (U0 ekseninde, 40 mm); lamalar GOZDEN ONCE. (2) scr_ltip: goz alt montaji (iki goz + kollar + coupler, ltip alttan) iki kafese birlikte arkadan kayar (supurme 0-100 mm serbest, kapak acik/kapali); kapak servosu gozlerden SONRA (servo yolu serbest, lamalar bosta cevrilir). (3) scr_lap_up1: ust bindirmede TEK civata x 10.3 (kanat kafa yoluna 0.7 mm biniyordu); bindirme vidalari gozlerden once, kapaklar KAPALI. Degisen STL: lid_up_L, lid_up_R. Sonuc: sirali 0 imkansiz / 0 engel; 3 uyari (M3 pan kafa SG90 govdesine ~0.15 mm, bilinen).

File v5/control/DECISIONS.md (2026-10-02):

# Project Eye v5 — Elektronik/Yazılım kararları

> **v5 notu:** v5 yalnız bağlantıları somunlu yaptı; kinematik v4 ile birebir aynı (`v5/cad/out/kinematics.json`). Bu klasör v4 yazılımının kopyası, banner `EYE v5 READY`. Aşağıdaki "v4" ifadeleri v5 için de geçerli.

v4 yazılımı, **v3'ün birebir kopyasıdır** (`../../v3/control`, v3'e dokunulmadı) ve v4 mekaniğine
uyarlanmıştır. v3'ün (ve v2'nin) protokol yorumları ve güvenlik kuralları aynen geçerlidir:
`../../v3/control/DECISIONS.md`. Aşağıda yalnızca v3'e göre farklar var.

## Kanallar
Aynı: 0 `EYE_YAW` D3, 1 `EYE_PITCH` D5, 2 `LIDS` D6. Fark: LIDS artık **dört kapağı** (2 üst + 2 alt)
tek servo ve dört-çubukla sürüyor (alt kapaklar ters yönde). Yazılım açısından hâlâ tek kanal,
`lids(openness)`; wink yok.

## Firmware limitleri = `v4/cad/out/kinematics.json → limits_checked`, pay yok

| Kanal | Min | Max | v3 |
|---|---|---|---|
| EYE_YAW | 65.0 | 115.0 | aynı (servo = 90 − yaw) |
| EYE_PITCH | 70.0 | 110.0 | aynı |
| LIDS | **77.71** | **102.29** | 67.5–112.5 |

LIDS: 102.29 kapalı, 77.71 açık. Dört-çubuk tablosu (11 satır) doğrusal değil; tablo modunda
kapak açısı tablodan (kalibrasyona oturtularak) hesaplanır, tablo satırları aynen üretilir (testli).
Derleme: flash 9538 B (%29), RAM 552 B (%26).

## `lid_follow_pitch` varsayılanı 0.0 [mekanik ajan uyarısı]
v4'te kapaklar **pitch çerçevesinde**: göz aşağı/yukarı bakınca kapaklar mekanik olarak birlikte
döner. Yazılımdaki pitch takibi bunun **üstüne** eklenirdi (çift takip). Bu yüzden:
- `settings.json` ve `DEFAULT_SETTINGS`: `behaviour.lid_follow_pitch = 0.0`.
- Firmware idle: `IDLE_LID_FOLLOW_PITCH = 0.0` (sim.py aynı; `test_firmware_sync` settings ile eşitliği kontrol eder).
- Formül ve kod yolu duruyor; ince ayar gerekirse küçük bir değer (ör. 0.1) settings.json'dan verilebilir.
  Test: k = 0 iken pitch değişse de LIDS servo açısı değişmiyor.

## Port el sıkışması: yalnızca banner [v3'ten fark]
- Kabul: yalnızca `EYE v5 READY`. Red: `READY` (Lunar gimbal), `EYE v2 READY`, `EYE v3 READY`.
- v2/v3'te banner gelmezse `?` gönderilip `STATE` kabul ediliyordu. v3 kartı da aynı biçimde
  3 açılı `STATE` döndürdüğü için bu yol v3 ile v4'ü **ayıramaz** → v4'te kaldırıldı.
  El sıkışma sırasında hiçbir porta hiçbir şey yazılmaz (testli).
- Bedeli: port açılınca resetlenmeyen bir kart (DTR otomatik reset kapalı klon) bulunamaz → sim'e düşer.
  Uno'lar pyserial ile açılınca resetlenir. Gerekirse kartın reset tuşuna portu açarken basın.
  Protokolü değiştirmemek için STATE'e sürüm alanı eklenmedi.

## settings.json
v3 şemasıyla aynı (3 kanal; LIDS'te `closed/open/min/max/invert`). Değerler v4
`settings_suggestion` ile birebir (`_note` alanları hariç), `lid_follow_pitch` 0.0.

## Doğrulanmayanlar
Hiçbir şey gerçek donanımda denenmedi: servo yönleri (yaw invert), dört-çubuk kapak açıları,
SG90'ın dört-çubuğu (iletim açısı ~47°) sürtünmeyle zorlanmadan çevirip çeviremediği, güç, Uno el sıkışması.

## D2 butonu (kullanıcı, 2026-09-30)
Buton D2 ↔ GND (dahili pull-up, 40 ms debounce). Açılışta **nötr** (idle kapalı; önceden 2 sn sessizlikten sonra kendiliğinden başlıyordu). Butona basınca doğal hareket (idle) hemen başlar, tekrar basınca nötr poza (gözler merkez, kapak %80) döner ve idle kapalı kalır. Karttaki LED (D13) idle açıkken yanar. `A 1`/`A 0` aynı anahtarı değiştirir (PC bağlanınca `A 1` gönderir). Buton seriye yazmaz. sim.py `press_button()` + `ButtonTests`.

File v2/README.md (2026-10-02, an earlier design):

# Project Eye v2

İki göz, dört bağımsız kapak, 6 × SG90, Arduino Uno. Esin kaynakları: InMoov "Advanced Eye Mechanism"
(Dakota76) ve Will Cogley'in 6 servolu göz mekanizması. Parçalar sıfırdan, parametrik olarak tasarlandı.

**Görmek için:** Epic panelde Project Eye → sürüm **v2** → Project Eye. `model.html` açılır: gerçek parçalar,
hareket kontrolü, canlı mod, kırpma ve servo açıları.

## Durum

| İş kolu | Durum | Doğrulama |
|---|---|---|
| Mekanik (`cad/`) | Tamam | 117 pozda çakışma **0**; en dar eklem dışı boşluk 0.173 mm; bütün katılar geçerli, duvar ≥1.2 mm |
| Firmware (`firmware/`) | Tamam | `arduino:avr:uno` derleniyor |
| Yazılım (`control/`) | Tamam | 89 unittest geçiyor (≈1900 pozda sınır aşımı yok), yüz takibi webcam'de denendi |
| Baskı toleransları | **Bekliyor** | Ender 3 Neo'da tolerans testi (`cad/tolerance/TEST.md`) |
| Gerçek donanım | **Denenmedi** | Servo yönleri, limitler, güç, montaj |

## Sıra

1. **Tolerans testi:** `cad/tolerance/out/*.stl` bas, `cad/tolerance/TEST.md`'ye göre dene ve sonucu raporla
   (`A3 B4 C2 ...`). Toleranslar `cad/params.py`'ye yazılır, bütün parçalar yeniden üretilir.
2. **Parçaları bas:** `cad/out/stl/` (23 parça, baskı yönüne çevrilmiş). Malzeme ve yön: `cad/BOM.md` §1.
3. **Malzemeleri al:** `cad/BOM.md` §2–4. 50 M2 vida, 4 × Ø2×12 pim, 4 RC rotil topu, 6 SG90, 5 V ≥3 A kaynak.
4. **Firmware'i yükle:** `control/README.md` → Firmware. Lunar gimbal'inin portuna yükleme.
5. **Montaj:** `cad/BOM.md` §5. Servolar 90°'deyken kollar **bağlantıya dik** takılır.
6. **Kalibrasyon:** `control/calibrate.py`. Başlangıç değerleri `cad/out/kinematics.json → settings_suggestion`.
7. **Çalıştır:** `control/eye_control.py` (demo) veya `control/face_follow.py` (yüz takibi).

## Dosyalar

| Yol | İçerik |
|---|---|
| `SPEC.md` | İki iş kolunun sözleşmesi: koordinatlar, kanal/pin haritası, seri protokol, ayar şeması |
| `cad/params.py` | Bütün ölçüler ve toleranslar tek yerde (`[TOL]` etiketliler test baskısıyla güncellenecek) |
| `cad/eye_v2.py` · `kin.py` · `check.py` | Parçalar + montaj · kinematik · çakışma taraması |
| `cad/out/step/` · `stl/` · `glb/` | Fusion için STEP (parça + `assembly.step`) · basılacak STL · görüntüleyici için GLB |
| `cad/out/kinematics.json` | Servo açısı ↔ göz/kapak açısı tabloları, köşe sınırları, ayar önerisi |
| `cad/out/check_report.txt` · `renders/` | Kontrol raporu · 9 kontrol görüntüsü |
| `cad/BOM.md` · `cad/DECISIONS.md` | Malzeme listesi + montaj sırası · tasarım kararları ve şartnameden sapmalar |
| `firmware/project_eye_v2/` | Uno firmware'i |
| `control/` | `eye_control` · `calibrate` · `face_follow` · `sim` · testler; ayrıntı `control/README.md` |
| `settings.json` | Kalibrasyon ve davranış ayarları (panelde ⚙) |
| `viewer/` | `model.html`'i üreten betik ve şablon. Model değişince: `build_viewer.py` |

## Bilinen riskler

- **Köşelerde yukarı-aşağı çapraz etkisi (çözüldü, donanımda denenmedi):** Firmware sınırları mekanik güvenli
  değerlere indirildi (pitch 63.17–121.62°). `eye_control` pitch servosunu `kinematics.json`'daki 2B tablodan
  hesaplıyor ve hiçbir yolda sınır dışı açı göndermiyor. Sabit sınır yüzünden göz ortada (yaw=0) −20…+23°'ye kadar iner.
- **0.173 mm boşluk** (göz çatalı ↔ sabit çatal, köşe pozunda) baskı toleransı mertebesinde. İlk montajda köşede sürtünme var mı bakılmalı.
- **Denenmemiş geçmeler:** Basılı rotil yuvası (pitch çubuğu) ve kapakların küçük destekli baskısı.
- **Tedarikte ölçülmesi gerekenler:** SG90'ın datasheet dışı ölçüleri, servo kolunda r=10 deliği, rotil topu ölçüleri.
- **Hesaplanmadı:** Servo torku. İris yalnızca görsel.

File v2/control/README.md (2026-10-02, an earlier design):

# Project Eye v2 — Kontrol yazılımı ve firmware

İki göz + dört kapak, 6 × SG90, Arduino Uno. Sözleşme: `../SPEC.md` (§4 kanal/pin,
§5 seri protokol, §6 settings.json). Kararlar ve sapmalar: `DECISIONS.md`.

> **Durum:** Firmware derleniyor, PC yazılımı firmware simülatörüne karşı test edildi.
> **Gerçek donanımda henüz denenmedi** (servo yönleri, limitler, güç davranışı doğrulanmadı).

## Dosyalar

| Dosya | Ne yapar | Bağımlılık |
|---|---|---|
| `../firmware/project_eye_v2/project_eye_v2.ino` | Uno firmware: protokol, limitler, 600°/s hız sınırı, idle "canlı" mod | Servo (Arduino çekirdeği) |
| `eye_control.py` | Seri sürücü, port bulma + el sıkışma, kalibrasyon, `look/lids/blink/wink/update` | pyserial (yoksa sim) |
| `sim.py` | Firmware'in Python eşdeğeri + sahte seri port | stdlib |
| `calibrate.py` | Kanal kanal etkileşimli kalibrasyon → `../settings.json` | pyserial, Windows konsolu |
| `face_follow.py` | Webcam → BlazeFace → en büyük yüz → bakış | opencv, mediapipe (Lunar venv) |
| `tests/` | 89 unittest: protokol, formüller, kinematik tablo, davranış, uçtan uca, .ino↔sim↔kinematics senkronu | stdlib |

## Kurulum

```powershell
# eye_control / calibrate / sim / testler için (yalnızca pyserial):
python -m venv C:\Users\LENOVO\epic-project\.venv-ctl
C:\Users\LENOVO\epic-project\.venv-ctl\Scripts\python.exe -m pip install pyserial
# face_follow için Lunar'ın venv'i (mediapipe + opencv + pyserial hazır):
#   C:\Users\LENOVO\lunar-tracker\.venv\Scripts\python.exe
```

`.venv-ctl` bu makinede kuruldu (pyserial 3.5).

## Kablolama

| Kanal | İsim | Uno pini |
|---|---|---|
| 0 | EYE_YAW | D3 |
| 1 | EYE_PITCH | D5 |
| 2 | LID_UL (sol üst) | D6 |
| 3 | LID_LL (sol alt) | D9 |
| 4 | LID_UR (sağ üst) | D10 |
| 5 | LID_LR (sağ alt) | D11 |

- SG90 kablo: **turuncu** = sinyal → pin, **kırmızı** = +5 V (harici), **kahverengi** = GND.
- Servolar **harici 5 V ≥ 3 A** kaynaktan beslenir. Uno'nun 5 V pininden 6 servo
  **beslenmez** (USB ~500 mA; tek SG90 zorlanmada ~650 mA çeker).
- Harici kaynağın **GND'si Uno GND'sine bağlanır** (ortak toprak; yoksa sinyal referanssız kalır).
- Harici +5 V'u Uno'nun 5 V pinine bağlamayın; Uno USB'den beslenir.
- Öneri: servo besleme hattına 470–1000 µF elektrolitik kondansatör (ani akım titremesini keser).
- Ölü nokta kuralı (§4): nötr konumda her servo kolu itme çubuğuna dik olmalı —
  kolları takmadan önce firmware'i açıp servoları nötre getirin (açılışta gözler 90°).

## Firmware

```powershell
& "C:\Users\LENOVO\AppData\Local\Programs\Arduino IDE\resources\app\lib\backend\resources\arduino-cli.exe" `
  compile --fqbn arduino:avr:uno C:\Users\LENOVO\epic-project\modules\project-eye\v2\firmware\project_eye_v2
# Yükleme (kart takılıyken, doğru portla! Lunar gimbal'inin portuna yüklemeyin):
#   ... upload -p COMx --fqbn arduino:avr:uno <aynı klasör>
```

Derleme: flash 9724 B (%30), RAM 651 B (%31), uyarı yok.

**Bakış eşlemesi:** `cad/out/kinematics.json` varsa göz servoları yaw×pitch 2B tablosundan
(çift doğrusal, köşe çapraz etkisi telafili), kapaklar 4-çubuk tablosundan hesaplanır;
yoksa SPEC §6 doğrusal formülü. Firmware limiti yüzünden yaw=0'da göz pitch'i −20…+23°,
yaw ±30'da tam ±25° (ayrıntı: DECISIONS.md).
Seri monitörden elle deneme (115200, satır sonu LF): `?`, `S 90 90 100 90 80 90`, `A 0`, `D`.

## Çalıştırma

`control` klasöründen:

```powershell
$py = "C:\Users\LENOVO\epic-project\.venv-ctl\Scripts\python.exe"
& $py eye_control.py            # donanımı bul (yoksa sim) ve kısa demo hareketi
& $py eye_control.py --sim      # donanımsız
& $py calibrate.py              # kalibrasyon (--sim ile prova, --port COM5)
& $py -m unittest discover -s tests -v

$env:PYTHONUTF8 = "1"
C:\Users\LENOVO\lunar-tracker\.venv\Scripts\python.exe face_follow.py          # --sim, --port COM5, --camera 1, --mirror
```

- **Port:** `settings.json` → `"serial_port": "auto"` her portu `EYE v2 READY`
  el sıkışmasıyla doğrular; Lunar gimbal'i (`READY`) reddedilir. Tarama bir Uno'yu
  resetleyebileceği için sabit port yazmak (`"COM5"`) ya da `EYE_EXCLUDE_PORTS=COM3` önerilir.
- **face_follow tuşları:** `q`/ESC çıkış, pencere X ile kapanır, `b` kırp, `l`/`r` wink,
  `m` ayna, `h` kontrolü firmware idle'ına bırak/geri al, `d` servoları bırak.
  Aynı anda tek kopya çalışır (kamera + COM kilidi).
- **calibrate tuşları:** `1..6` kanal, ←/→ ±1°, ↑/↓ ±5°, `,`/`.` ±0.2°; göz: `c` center,
  `n` min, `x` max; kapak: `k` closed, `o` open; `i` invert, `g` kayıtlılar arası gez,
  `t` test, `z` detach, `s` kaydet, `q` çık.

## Kod içinden

```python
from eye_control import EyeController
eye = EyeController()          # port: settings.json; bulamazsa sim
eye.look(0.5, -0.2)            # -1..1, +u robotun sağı, +v yukarı
eye.lids(0.8, left=0.4)        # taban açıklık, göz bazında ezilebilir
eye.blink(); eye.wink("left")
while True:
    eye.update()               # her karede: sakkad sınırı, kırpma, kapak takibi, S gönderimi
```

## Kalibrasyon sonrası yapılacaklar

1. `calibrate.py` ile altı kanalın gerçek değerlerini `settings.json`'a yaz.
2. Firmware `LIMIT_MIN/MAX` şu an `cad/out/kinematics.json` mekanik sınırları (pay yok;
   pitch 63.17–121.62 yaw'dan bağımsız güvenli aralık). Montajda sınırlar farklı çıkarsa
   yalnızca **daraltın**; `IDLE_LID_CLOSED/OPEN` ve `IDLE_EYE_*`'ı yeni settings.json'a çekin,
   aynı sabitleri `sim.py`'de güncelleyin (`tests/test_firmware_sync.py` ve
   `tests/test_kinematics.py` farkı yakalar).
3. Derle, yükle, `face_follow.py` ile dene.

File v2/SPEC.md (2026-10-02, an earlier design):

# Project Eye v2 — Tasarım Şartnamesi

v1: tek göz, kardan mafsallı, 2 SG90 (sadece 3D görselleştirme).
v2: **iki göz + dört kapak, 6 SG90, basılabilir parçalar, firmware ve kontrol yazılımı.**
Esin: InMoov "Advanced Eye Mechanism" (Dakota76: 6×SG90, kapaklı, gözler bağımsız sağ-sol)
ve Will Cogley'in göz mekanizması (6 servo: 2 göz ekseni + 4 kapak).

Bu belgedeki **SABİT** maddeler iki iş kolunun (mekanik / elektronik-yazılım) ortak sözleşmesidir.
Değiştirmek gerekirse gerekçesiyle `DECISIONS.md`'ye yazılır.

## 1. Koordinat sistemi (SABİT)
- Birim **mm**, derece.
- Orijin: iki göz merkezinin tam ortası.
- **+X = robotun sağı** (karşıdan bakana göre sol), **+Y = yukarı**, **+Z = ileri** (yüzün baktığı yön).
- Sol göz merkezi `(-31.5, 0, 0)`, sağ göz merkezi `(+31.5, 0, 0)` → göz bebekleri arası (IPD) **63**.
- Açılar: **yaw +** = robot kendi sağına bakar; **pitch +** = yukarı bakar.
  Kapak açısı: **0 = tam kapalı**, **1 = tam açık** (normalize).

## 2. Göz (v1'den devralınan, SABİT)
- Göz küresi Ø**24**, iris Ø12, bebek Ø4 (yetişkin ortalaması).
- Her göz kendi merkezinde **kardan mafsalı** ile döner:
  göbek 8×8×8, 4× **M2×5** (göbeğe 2.5 mm girer), çatal kolu 2 mm, göbek-kol boşluğu 0.5.
- Sabit çatal arkadan bir direkle çerçeveye bağlanır.
- Hareket aralığı: **yaw ±30°, pitch ±25°**.
- Göz kabuğu: v1'de yarım küreydi. v2'de kapakların arkasında görünmemesi için öne bakan kısım
  küre olmalı; arka açıklık serbest (mafsal ve itme bağlantısı için).

## 3. Kapaklar
- Göz başına **üst + alt** kapak. Toplam 4 kapak.
- Kapaklar **küre kabuk dilimi**dir ve **gözün pitch ekseni etrafında** (göz merkezinden geçen X ekseni) döner.
  - İç yarıçap = 12 + **0.6 boşluk**, kalınlık **1.2**.
  - Pim yerleri gözün iki yanında, çerçeveye bağlı.
- Kapalıyken üst ve alt kapak kenarları gözün yatay orta çizgisinin **hafif altında** buluşur
  (insan gözünde kapaklar ortanın biraz altında kapanır). Kapanma açısı parametrik olsun.
- Açıkken üst kapak irisin üstünden ~1–2 mm örter; bakış yukarı-aşağı gittikçe kapak onu takip edebilsin.

## 4. Servolar ve kanal haritası (SABİT)
6 × SG90 (Luxorparts datasheet: gövde 22.8×12.4, kulaklarla 32.0, kulak altı 15.6, gövde üstü 26.7,
mil gövde ucundan ≈5.8). Kol deliği aralığı 2 mm.

| Kanal | İsim | İşlev |
|---|---|---|
| 0 | `EYE_YAW` | İki gözün sağ-sol hareketi (bağlantı çubuğuyla birlikte) |
| 1 | `EYE_PITCH` | İki gözün yukarı-aşağı hareketi (birlikte) |
| 2 | `LID_UL` | Sol üst kapak |
| 3 | `LID_LL` | Sol alt kapak |
| 4 | `LID_UR` | Sağ üst kapak |
| 5 | `LID_LR` | Sağ alt kapak |

- Gözler birbirine **bağlıdır**: yaw ve pitch için birer ortak bağlantı çubuğu vardır, şaşılık yoktur.
- Kapaklar **bağımsızdır**: göz kırpma, uykulu bakış ve ifade üretilebilir.
- Arduino **Uno** pin haritası: D3, D5, D6, D9, D10, D11 → kanal 0..5.
- **Güç:** servolar harici **5 V ≥3 A** kaynaktan beslenir, GND Uno ile ortaktır.
  6 SG90'ın toplam zorlanma akımı USB'nin kaldıracağından fazladır.
- **Ölü nokta kuralı (v1 dersi):** nötr konumda her servo kolu itme çubuğuna **dik** olmalı.

## 5. Seri protokol (SABİT)
- **115200 baud**, satır sonu `\n`, ASCII.
- PC → Arduino:
  - `S a0 a1 a2 a3 a4 a5` — 6 kanalın **servo açısı** (derece, 0–180, ondalık kabul edilir).
    Kalibrasyon PC tarafında yapılır, Arduino ham açı alır.
  - `D` — detach: tüm servolar bırakılır.
  - `A 1|0` — Arduino'nun kendi başına "canlı" moda (idle) geçmesini aç/kapat.
  - `?` — durum sorgusu.
- Arduino → PC:
  - `OK` — geçerli komut.
  - `ERR <mesaj>` — geçersiz komut.
  - Açılışta `EYE v2 READY`.
  - `?` sorgusuna `STATE a0..a5 idle=<0|1>`.
- **Güvenlik:**
  - Açılar firmware içinde kanal başına **sabit mekanik limitlere** kırpılır.
  - Her kanal hedefe **hız sınırıyla** gider: en fazla 600°/s. Bu, SG90'ın datasheet hızına ve insan sakkadına yakın.
- **Idle:** Firmware **2 saniye** komut almazsa kendi başına yaşar: rastgele sakkadlar, 3–6 saniyede bir göz kırpma, yavaş nefes gibi kapak salınımı. İlk `S` komutunda PC kontrolü geri alır.

## 6. Kalibrasyon ve ayarlar: `settings.json` (SABİT şema)
```json
{
  "serial_port": "auto",
  "channels": {
    "EYE_YAW":   {"center": 90, "min": 60, "max": 120, "invert": false, "deg_per_unit": 30},
    "EYE_PITCH": {"center": 90, "min": 65, "max": 115, "invert": false, "deg_per_unit": 25},
    "LID_UL":    {"closed": 60, "open": 120, "invert": false},
    "LID_LL":    {"closed": 120, "open": 70, "invert": false},
    "LID_UR":    {"closed": 120, "open": 60, "invert": false},
    "LID_LR":    {"closed": 60, "open": 110, "invert": false}
  },
  "behaviour": {
    "blink_interval_s": [3, 6],
    "lid_follow_pitch": 0.6,
    "saccade_speed_deg_s": 500,
    "idle_after_s": 1.5
  }
}
```
- Gözler: `angle = center + clamp(u,-1,1) * deg_per_unit * (invert ? -1 : 1)`, ardından [min, max] aralığına kırpılır.
- Kapaklar: `angle = closed + openness * (open - closed)`.
- Değerler **örnek başlangıç değeridir**. Gerçek değerler montajdan sonra kalibrasyon aracıyla bulunur.

## 7. Dosya düzeni (SABİT)
```
modules/project-eye/v2/
  SPEC.md             bu belge
  DECISIONS.md        şartnameden sapmalar ve gerekçeleri (iki iş kolu da yazar)
  model.html          etkileşimli 3D görüntüleyici (panelin ana butonu bunu açar)
  settings.json       §6
  README.md           ürün sayfası: malzeme listesi (BOM), baskı ayarları, montaj, kablolama
  cad/                (MEKANİK iş kolu)
    eye_v2.py         CadQuery ile parametrik tüm parçalar + montaj
    params.py         tüm ölçüler tek yerde
    check.py          çakışma ve hareket taraması testleri
    out/step/*.step   Fusion 360'a aktarılabilir parçalar
    out/stl/*.stl     baskıya hazır parçalar (baskı yönüne döndürülmüş)
    out/glb/assembly.glb  (veya parça başına .glb) görüntüleyici için, hareketli parçalar ayrı düğüm
    out/renders/*.png kontrol görüntüleri
  firmware/           (ELEKTRONİK iş kolu)
    project_eye_v2/project_eye_v2.ino
  control/            (YAZILIM iş kolu)
    eye_control.py    seri sürücü + kalibrasyon + davranış (bakış, kırpma, kapak takibi)
    face_follow.py    webcam yüz takibi → bakış (Lunar'ın BlazeFace modelini kullanır)
    calibrate.py      kanal kanal kalibrasyon aracı (settings.json'a yazar)
    sim.py            donanım yokken sahte seri port (testler için)
    tests/
```

## 8. Doğrulama çıtası
- **Mekanik:**
  - Hareket aralığının köşelerinde (yaw ±30, pitch ±25) ve kapaklar açık/kapalıyken parça çiftleri arasında **çakışma hacmi 0**.
  - Minimum boşluk raporu.
  - Her parça tek parça **katı (valid solid)** olmalı.
  - Duvar kalınlıkları ≥1.2 mm.
- **Firmware:** `arduino-cli compile --fqbn arduino:avr:uno` hatasız geçmeli.
  Derleyici: `C:\Users\LENOVO\AppData\Local\Programs\Arduino IDE\resources\app\lib\backend\resources\arduino-cli.exe`
- **Yazılım:** `sim.py` ile protokol testleri geçmeli. Donanım gerektiren kısımlar donanım olmadan da çökmeden devre dışı kalmalı.

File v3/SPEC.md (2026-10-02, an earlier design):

# Project Eye v3 — POC Şartnamesi

**Amaç:** Kullanıcının elindeki malzemeyle, Ender 3 Neo'da güvenle basılıp hızlıca kurulabilen bir kavram kanıtı.
Kusursuzluk değil **basitlik ve sağlamlık**. Ölçüler v2'den serbestçe büyüyebilir. Sonra malzeme alınıp v2 çizgisine dönülecek.
Referans: v2 (`../v2/`, özellikle `v2/cad/` kodu ve `v2/cad/DECISIONS.md`). Bu tasarım v2'nin sadeleştirilmiş, büyütülmüş halidir.

## Eldeki malzeme (SABİT — başka bağlantı elemanı yok)
- **M4×10 yuvarlak kafa** (çok sayıda): eklem pimleri ve genel bağlantı.
- **M4×16 havşa (90° koni) kafa** (çok sayıda): taban ve kalın parçalar.
- **M3×10 yuvarlak kafa: sadece 14 adet.** Yalnızca M4'ün sığmadığı yerlerde.
- **M2 YOK. Somun YOK. Çelik pim YOK. Rotil/top YOK. Tel YOK.**
- SG90 servolar, kendi kol ve vidalarıyla (kol vidaları kol ↔ basılı parça bağlantısında kullanılabilir). Arduino Uno.
- Yazıcı: Creality Ender 3 Neo, 0.4 nozül, PLA, tabla 220×220.

## Kapsam
- **İki göz**, birbirine bağlı (şaşılık yok). Göz Ø**36**, göz merkezleri arası **95** (insan oranı ~2.6 × çap).
- **3 servo:**
  | Kanal | İsim | İşlev |
  |---|---|---|
  | 0 | `EYE_YAW` | İki göz birlikte sağ-sol |
  | 1 | `EYE_PITCH` | İki göz birlikte yukarı-aşağı |
  | 2 | `LIDS` | İki **üst** kapak birlikte (kırpma) |
- Alt kapaklar **yok** (maske/yüz plakası alt kapak şeklini sabit olarak verebilir).
- Hareket aralığı: yaw ±25°, pitch ±20°, kapak tam açık ↔ kapalı (göz kırpabilmeli).
- Koordinat sistemi v2 SPEC §1 ile aynı: mm, +X robotun sağı, +Y yukarı, +Z ileri, orijin iki göz merkezinin ortası.

## Basitlik kuralları (asıl amaç bunlar)
1. **Basılı top/rotil yuvası, sıkı geçme pim, kartal/snap-fit yok.** Her dönen eklem: **M4 vida = pim**.
   Vida sabit parçada `M4_PILOT` deliğine vidalanır, dönen parça `M4_RUN` deliğinde döner. İki parça arasında `AXIAL_GAP` boşluk.
2. **İtme çubukları basılı düz lama** (her iki ucunda M4_RUN delikli). 3B mafsal gerekiyorsa, dönme eksenleri
   hemen hemen paralel kalacak şekilde düzen kur ya da lamayı yeterince uzun ve esnek tut. Bunu `DECISIONS.md`'de gerekçelendir.
3. **Min. duvar 1.6 mm, min. detay 0.8 mm.** Destek gerektiren yerleri en aza indir, gerekiyorsa BOM'da belirt.
4. **Az parça:** hedef ≤ 15 farklı basılı parça. Her parça tablaya düz bir yüzle oturabilmeli.
5. Kardan mafsalı v2 mantığıyla kalabilir ama büyütülmüş: göbek ve çatal ölçüleri M4'e göre.
6. Servo kolları nötrde (90°) itme lamasına **dik** (ölü nokta dersi).

## Toleranslar (`params.py`'de adlandırılmış sabit, test sonucu gelince güncellenecek)
`M3_PILOT 2.7` · `M3_CLEAR 3.3` · `M4_PILOT 3.5` · `M4_RUN 4.3` · `M4_CSK_D 8.2` (90°) · `AXIAL_GAP 0.4` · `SERVO_POCKET_CLR 0.3`.
Tolerans testi: `cad/tolerance/` (kullanıcı basıyor).

## Çıktılar (v2 ile aynı düzen)
`cad/params.py`, `kin.py`, `eye_v3.py` (parçalar + montaj + `pose_transforms(yaw, pitch, lid)` + `servo_angles`),
`check.py` (çakışma taraması), `render.py`; `cad/out/{step,stl,glb,renders}/`, `glb/rig.json`, `kinematics.json`,
`check_report.txt`; `cad/BOM.md` (basılacak parçalar + vida sayıları: M3 ≤ 14 kontrolü!), `cad/DECISIONS.md`.

## Doğrulama
- Hareket aralığı taramasında çakışma 0; eklem dışı min. boşluk raporu (POC için ≥ 0.4 mm hedef, Ender 3 Neo).
- Bütün parçalar geçerli katı, duvar ≥ 1.6 mm.
- BOM'da M3 sayısı ≤ 14.

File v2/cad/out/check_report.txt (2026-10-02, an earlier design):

PROJECT EYE v2 - MEKANIK KONTROL RAPORU
uretim: check.py  |  ucgenleme toleransi 0.01 mm  |  kesisim esigi 0.01 mm3

1) KATI GECERLILIGI (OCC BRepCheck) + ucgen agi su gecirmezligi
   parca sayisi: 99 (basilan 29)
   gecersiz kati: yok
   basilan parcalarda tek-kati olmayan: yok
   su gecirmez olmayan ag: ['stud_pitch_L', 'stud_pitch_R', 'lid_UL', 'lid_UR', 'stud_rocker_L', 'stud_rocker_R', 'rod_pitch_L', 'rod_pitch_R']

2) GRUP ICI (birbirine sabit parcalar, notr poz) - kesisim >= esik:
   yok (temaslar: vida kafasi/yuzey, kulak/plaka vb. tasarim geregi 0 mesafe)

3) HAREKET TARAMASI: zorunlu 18 poz (yaw (-30.0, 0.0, 30.0) x pitch (-25.0, 0.0, 25.0) x kapak acik/kapali) + firmware-sinir pozlari 12 (pitch servosu guvenli sinirda 63.2/121.6, yaw -30..30) + yogun tarama 87 poz (yaw 10 deg, pitch 12.5 deg adim, kapak kapali/nominal/acik)
   kapak 'acik' = mekanik tam acik (ust kenar +38, alt kenar -45 deg), 'kapali' = kenarlar -5 deg'de bulusur (arada 1.5 deg)

   zorunlu pozlar:
   yaw    pitch  kapak    | cakisma | min bosluk (mm) | en yakin cift
   -30.0  -25.0  open     |       0 |           0.000 | lid_LL x scr_lidA_LL
   -30.0    0.0  open     |       0 |           0.000 | lid_LL x scr_lidA_LL
   -30.0   25.0  open     |       0 |           0.000 | lid_LL x scr_lidA_LL
     0.0  -25.0  open     |       0 |           0.000 | lid_LL x scr_lidA_LL
     0.0    0.0  open     |       0 |           0.000 | lid_LL x scr_lidA_LL
     0.0   25.0  open     |       0 |           0.000 | lid_LL x scr_lidA_LL
    30.0  -25.0  open     |       0 |           0.000 | lid_LL x scr_lidA_LL
    30.0    0.0  open     |       0 |           0.000 | lid_LL x scr_lidA_LL
    30.0   25.0  open     |       0 |           0.000 | lid_LL x scr_lidA_LL
   -30.0  -25.0  closed   |       0 |           0.000 | lid_LL x scr_lidA_LL
   -30.0    0.0  closed   |       0 |           0.000 | lid_LL x scr_lidA_LL
   -30.0   25.0  closed   |       0 |           0.000 | lid_LL x scr_lidA_LL
     0.0  -25.0  closed   |       0 |           0.000 | lid_LL x scr_lidA_LL
     0.0    0.0  closed   |       0 |           0.000 | lid_LL x scr_lidA_LL
     0.0   25.0  closed   |       0 |           0.000 | lid_LL x scr_lidA_LL
    30.0  -25.0  closed   |       0 |           0.000 | lid_LL x scr_lidA_LL
    30.0    0.0  closed   |       0 |           0.000 | lid_LL x scr_lidA_LL
    30.0   25.0  closed   |       0 |           0.000 | lid_LL x scr_lidA_LL
   -15.0  -21.2  open     |       0 |           0.000 | lid_LL x scr_lidA_LL
   -15.0   23.5  open     |       0 |           0.000 | lid_LL x scr_lidA_LL
     0.0  -20.3  open     |       0 |           0.000 | lid_LL x scr_lidA_LL
     0.0   23.0  open     |       0 |           0.000 | lid_LL x scr_lidA_LL
    15.0  -21.2  open     |       0 |           0.000 | lid_LL x scr_lidA_LL
    15.0   23.5  open     |       0 |           0.000 | lid_LL x scr_lidA_LL
   -15.0  -21.2  closed   |       0 |           0.000 | lid_LL x scr_lidA_LL
   -15.0   23.5  closed   |       0 |           0.000 | lid_LL x scr_lidA_LL
     0.0  -20.3  closed   |       0 |           0.000 | lid_LL x scr_lidA_LL
     0.0   23.0  closed   |       0 |           0.000 | lid_LL x scr_lidA_LL
    15.0  -21.2  closed   |       0 |           0.000 | lid_LL x scr_lidA_LL
    15.0   23.5  closed   |       0 |           0.000 | lid_LL x scr_lidA_LL
   yogun tarama: toplam cakisma 0; en kucuk bosluk 0.000 mm (lid_LL x scr_lidA_LL)

   TOPLAM CAKISMA (>= 0.01 mm3): 0
   EN KUCUK BOSLUK (tum pozlar, farkli gruplar): 0.000 mm  ('lid_LL', 'scr_lidA_LL', -30.0, -25.0, 'open')

4a) EKLEM DISI (birbirine degmemesi gereken) CIFTLERDE EN DAR 25 BOSLUK - asil carpisma payi:
     0.173  eye_fork_L x fixed_fork_L   @ yaw 30.0 pitch -25.0 open
     0.173  eye_fork_R x fixed_fork_R   @ yaw -30.0 pitch -25.0 open
     0.182  lid_UL x lid_LL   @ yaw -30.0 pitch -25.0 closed
     0.182  lid_UR x lid_LR   @ yaw -30.0 pitch -25.0 closed
     0.290  eye_shell_R x fixed_fork_R   @ yaw 30.0 pitch 25.0 open
     0.290  eye_shell_L x fixed_fork_L   @ yaw -30.0 pitch 25.0 open
     0.400  lid_UL x back_frame   @ yaw -30.0 pitch -25.0 open
     0.400  lid_UR x back_frame   @ yaw -30.0 pitch -25.0 open
     0.490  scr_pupil_L x lid_LL   @ yaw 30.0 pitch -25.0 closed
     0.490  scr_pupil_R x lid_LR   @ yaw -30.0 pitch -25.0 closed
     0.490  scr_pupil_L x lid_UL   @ yaw -30.0 pitch 25.0 closed
     0.490  scr_pupil_R x lid_UR   @ yaw 30.0 pitch 25.0 closed
     0.580  eye_shell_L x rod_pitch_L   @ yaw 30.0 pitch -25.0 open
     0.580  eye_shell_R x rod_pitch_R   @ yaw -30.0 pitch -25.0 open
     0.586  eye_shell_L x lid_UL   @ yaw -10 pitch 12.5 nominal
     0.586  eye_shell_R x lid_UR   @ yaw 10 pitch 12.5 nominal
     0.588  eye_shell_L x lid_LL   @ yaw -10 pitch -12.5 closed
     0.588  eye_shell_R x lid_LR   @ yaw 10 pitch -12.5 closed
     0.590  eye_shell_L x yaw_lever_L   @ yaw -15 pitch -21.25 open
     0.590  eye_shell_R x yaw_lever_R   @ yaw -15 pitch -21.25 open
     0.683  eye_shell_L x rocker   @ yaw 30.0 pitch -25.0 open
     0.683  eye_shell_R x rocker   @ yaw -30.0 pitch -25.0 open
     0.697  eye_shell_R x mask   @ yaw 20 pitch 25 closed
     0.697  eye_shell_L x mask   @ yaw -20 pitch 25 closed
     0.700  scr_lidB_UR x horn_lid_LR   @ yaw -30 pitch -25 nominal
4b) EKLEM CIFTLERI (tasarim geregi temas/yatak boslugu; bilgi icin, en dar 15):
     0.000  lid_LL x scr_lidA_LL
     0.000  lid_LR x scr_lidA_LR
     0.000  servo_lid_UL x horn_lid_UL
     0.000  link_UL x scr_lidA_UL
     0.000  link_UL x scr_lidB_UL
     0.000  servo_lid_LL x horn_lid_LL
     0.000  link_LL x scr_lidB_LL
     0.000  servo_lid_UR x horn_lid_UR
     0.000  link_UR x scr_lidA_UR
     0.000  link_UR x scr_lidB_UR
     0.000  servo_lid_LR x horn_lid_LR
     0.000  link_LR x scr_lidB_LR
     0.000  servo_yaw x horn_yaw
     0.000  servo_pitch x horn_pitch
     0.044  stud_pitch_R x rod_pitch_R

5) ET KALINLIGI (isin yontemi, basilan parcalar; min / %1 / %5 yuzdelik, mm):
   not: kenar ve kose yakinindaki egik isabetler ayiklanir; %1 degeri gercek ince bolgeyi daha iyi temsil eder.
   eye_shell_L              min  0.71  %1  1.59  %5  1.59   (en ince ~ [-30.5  -0.4  10.3])
   eye_fork                 min  0.50  %1  1.27  %5  1.35   (en ince ~ [-31.8   1.3   7.9])
   gobek                    min  2.00  %1  2.00  %5  2.90   (en ince ~ [-32.5   0.4  -1. ])
   yaw_lever                min  1.20  %1  1.20  %5  1.20   (en ince ~ [-29.5  18.    0.6])
   fixed_fork               min  1.07  %1  1.20  %5  1.84   (en ince ~ [-31.5   4.6   2.4])
   eye_shell_R              min  0.71  %1  1.59  %5  1.59   (en ince ~ [30.4 -0.4 10.3])
   lid_upper_L              min  1.19  %1  1.20  %5  1.20   (en ince ~ [-41.1   0.2   8.1])
   lid_lower_L              min  1.20  %1  1.20  %5  1.20   (en ince ~ [-34.8  -1.7  13.3])
   lid_upper_R              min  1.19  %1  1.20  %5  1.20   (en ince ~ [42.1  0.2  8.9])
   lid_lower_R              min  1.20  %1  1.20  %5  1.20   (en ince ~ [41.6 -4.2  6.2])
   lid_link_upper           min  1.40  %1  1.40  %5  1.40   (en ince ~ [-52.3  -9.6 -54.1])
   lid_link_lower           min  1.40  %1  1.40  %5  1.65   (en ince ~ [-48.7 -25.7 -42.1])
   yaw_coupler              min  1.85  %1  1.85  %5  1.86   (en ince ~ [-32.5  18.8  -9.4])
   rocker                   min  2.10  %1  2.70  %5  3.00   (en ince ~ [ 38.6 -16.9 -16.6])
   pitch_link_L             min  1.55  %1  1.55  %5  1.55   (en ince ~ [ 2.4 -0.2 20.2])
   pitch_link_R             min  1.55  %1  1.55  %5  1.55   (en ince ~ [ 0.3 -2.4 19.8])
   back_frame               min  1.50  %1  2.92  %5  3.00   (en ince ~ [0.  1.1 7.5])
   mount_pitch_servo        min  1.50  %1  2.65  %5  3.00   (en ince ~ [-62.3 -32.1  -4.2])
   rocker_bearing           min  1.60  %1  2.57  %5  3.00   (en ince ~ [ 48.1 -38.6 -22.1])
   mount_lid_servos_L       min  1.50  %1  1.62  %5  2.65   (en ince ~ [-32.4  -1.  -67.2])
   mount_lid_servos_R       min  1.50  %1  1.92  %5  2.65   (en ince ~ [ 36.2  -0.8 -42.6])
   mask                     min  1.60  %1  3.00  %5  3.00   (en ince ~ [ 19.4 -38.6  12.2])
   base                     min  1.80  %1  4.00  %5  4.00   (en ince ~ [ 67.  -43.  -34.6])

6) BASKI YONU ve DESTEK (eye_v2 print_R yonunde; tablaya degmeyen, yatayla 45 deg'den yatik asagi yuzey alani):
   eye_shell_L              sarkma   227.4 mm2  tabla temas   271.5 mm2  boyut [23.8 43.3 18.2]  -> buyuk sarkma (BOM.md aciklamasi)
   eye_fork                 sarkma    45.9 mm2  tabla temas    24.0 mm2  boyut [13.   6.  12.4]  -> incele: kopru veya kucuk agac destek (BOM.md)
   gobek                    sarkma    19.7 mm2  tabla temas    64.0 mm2  boyut [8. 8. 8.]  -> ihmal edilebilir (<30 mm2: delik tavani/kisa kopru)
   yaw_lever                sarkma    10.0 mm2  tabla temas    84.1 mm2  boyut [ 6.6 16.6 14. ]  -> ihmal edilebilir (<30 mm2: delik tavani/kisa kopru)
   fixed_fork               sarkma    76.4 mm2  tabla temas   125.5 mm2  boyut [13. 13. 35.]  -> incele: kopru veya kucuk agac destek (BOM.md)
   eye_shell_R              sarkma   227.4 mm2  tabla temas   271.5 mm2  boyut [23.8 43.3 18.2]  -> buyuk sarkma (BOM.md aciklamasi)
   lid_upper_L              sarkma    68.6 mm2  tabla temas   100.2 mm2  boyut [20.9 21.3 40.8]  -> incele: kopru veya kucuk agac destek (BOM.md)
   lid_lower_L              sarkma    62.2 mm2  tabla temas    96.5 mm2  boyut [17.3 15.7 30. ]  -> incele: kopru veya kucuk agac destek (BOM.md)
   lid_upper_R              sarkma    68.6 mm2  tabla temas   100.2 mm2  boyut [20.9 21.3 40.8]  -> incele: kopru veya kucuk agac destek (BOM.md)
   lid_lower_R              sarkma    62.2 mm2  tabla temas    96.5 mm2  boyut [17.3 15.7 30. ]  -> incele: kopru veya kucuk agac destek (BOM.md)
   lid_link_upper           sarkma     0.0 mm2  tabla temas   254.4 mm2  boyut [53.5  6.2  2. ]  -> ihmal edilebilir (<30 mm2: delik tavani/kisa kopru)
   lid_link_lower           sarkma     0.0 mm2  tabla temas   270.3 mm2  boyut [54.1 19.9  2. ]  -> ihmal edilebilir (<30 mm2: delik tavani/kisa kopru)
   yaw_coupler              sarkma     0.0 mm2  tabla temas   393.8 mm2  boyut [69.  6.  2.]  -> ihmal edilebilir (<30 mm2: delik tavani/kisa kopru)
   rocker                   sarkma    24.7 mm2  tabla temas   753.2 mm2  boyut [85.  28.2 10.3]  -> ihmal edilebilir (<30 mm2: delik tavani/kisa kopru)
   pitch_link_L             sarkma   106.8 mm2  tabla temas     7.6 mm2  boyut [28.  8.  8.]  -> incele: kopru veya kucuk agac destek (BOM.md)
   pitch_link_R             sarkma   106.8 mm2  tabla temas     7.6 mm2  boyut [28.  8.  8.]  -> incele: kopru veya kucuk agac destek (BOM.md)
   back_frame               sarkma   131.3 mm2  tabla temas  2008.6 mm2  boyut [138.   48.   48.5]  -> incele: kopru veya kucuk agac destek (BOM.md)
   mount_pitch_servo        sarkma    11.6 mm2  tabla temas   774.1 mm2  boyut [47.  22.8 11. ]  -> ihmal edilebilir (<30 mm2: delik tavani/kisa kopru)
   rocker_bearing           sarkma     5.8 mm2  tabla temas   167.9 mm2  boyut [12.  14.3 10. ]  -> ihmal edilebilir (<30 mm2: delik tavani/kisa kopru)
   mount_lid_servos_L       sarkma    11.6 mm2  tabla temas  1189.2 mm2  boyut [35.  51.  11.1]  -> ihmal edilebilir (<30 mm2: delik tavani/kisa kopru)
   mount_lid_servos_R       sarkma    11.6 mm2  tabla temas  1189.2 mm2  boyut [35.  51.  11.1]  -> ihmal edilebilir (<30 mm2: delik tavani/kisa kopru)
   mask                     sarkma    11.9 mm2  tabla temas  7982.5 mm2  boyut [128.  67.  11.]  -> ihmal edilebilir (<30 mm2: delik tavani/kisa kopru)
   base                     sarkma   120.6 mm2  tabla temas 14527.8 mm2  boyut [158.  93.   4.]  -> incele: kopru veya kucuk agac destek (BOM.md)

7) SERVO ACILARI (kontrol pozlarinda, derece):
   yaw    0 pitch    0: EYE_YAW   90.0  EYE_PITCH   90.0
   yaw  -30 pitch    0: EYE_YAW   60.0  EYE_PITCH   90.0
   yaw   30 pitch    0: EYE_YAW  120.0  EYE_PITCH   90.0
   yaw    0 pitch  -25: EYE_YAW   90.0  EYE_PITCH   56.7
   yaw    0 pitch   25: EYE_YAW   90.0  EYE_PITCH  125.6
   yaw  -30 pitch  -25: EYE_YAW   60.0  EYE_PITCH   63.2
   yaw   30 pitch   25: EYE_YAW  120.0  EYE_PITCH  121.6
   kapak closed  : LID_UL   64.4  LID_LL  113.8  LID_UR  115.6  LID_LR   66.2
   kapak nominal : LID_UL   96.2  LID_LL   86.8  LID_UR   83.8  LID_LR   93.2
   kapak open    : LID_UL  115.6  LID_LL   66.2  LID_UR   64.4  LID_LR  113.8

SONUC: cakisma 0, eklem disi en kucuk bosluk 0.173 mm (eye_fork_L x fixed_fork_L @ (30.0, -25.0, 'open')), gecersiz kati 0, 1.2 alti et (yuzdelik %1) 0 parca []
sure 395 s

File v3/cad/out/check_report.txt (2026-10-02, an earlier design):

PROJECT EYE v3 (POC) - MEKANIK KONTROL RAPORU
uretim: check.py | ucgenleme 0.01 mm | kesisim esigi 0.01 mm3 | eklem disi bosluk hedefi 0.4 mm

1) KATI GECERLILIGI
   parca sayisi 52 (basilan 14, farkli basilan STL 12: ['base', 'coupler', 'eye', 'eye_lever', 'frame_L', 'frame_R', 'lid_L', 'lid_R', 'lid_carrier', 'pivot_bracket', 'yaw_crank', 'yaw_mount'])
   gecersiz kati: yok | tek-kati olmayan basilan: yok | su gecirmez olmayan ag: yok

2) GRUP ICI (birbirine sabit parcalar, notr poz) - kesisim >= esik:
   ! eye_lever_L x scr_lock_L: 0.014 mm3
   ! eye_lever_R x scr_lock_R: 0.014 mm3
   ! frame_L x scr_ptop_L: 0.014 mm3
   ! frame_L x scr_pbot_L: 0.018 mm3
   ! frame_R x scr_ptop_R: 0.014 mm3
   ! frame_R x scr_pbot_R: 0.018 mm3
   ! servo_pitch x scr_m3_pitch0: 1.220 mm3
   ! servo_pitch x scr_m3_pitch1: 1.220 mm3
   ! servo_yaw x scr_m3_yaw0: 1.220 mm3
   ! servo_yaw x scr_m3_yaw1: 1.220 mm3
   ! scr_ym_L27 x yaw_mount: 0.014 mm3
   ! scr_ym_L40 x yaw_mount: 0.014 mm3
   ! scr_ym_R27 x yaw_mount: 0.014 mm3
   ! scr_ym_R40 x yaw_mount: 0.014 mm3
   ! servo_lid x scr_m3_lid0: 1.220 mm3
   ! servo_lid x scr_m3_lid1: 1.220 mm3
   ! scr_brk_81 x base: 0.014 mm3
   ! scr_brk_67 x base: 0.014 mm3
   not: ~0.01-0.02 mm3 = havsa kafa konisi ile yuvasi ayni yuzey (ucgenleme). scr_m3_* x servo_* ~1.2 mm3 GERCEK:
        SG90 kulak deligi govdeden ~2.5 mm; M3 kafa (O5.6) govde duvarina ~0.3 mm biniyor (DECISIONS.md, risk).

3) HAREKET TARAMASI: zorunlu 18 poz (yaw (-25.0, 0.0, 25.0) x pitch (-20.0, 0.0, 20.0) x kapak acik/kapali) + ara tarama 57 poz (yaw 12.5, pitch 10 deg adim, kapak 0/0.5/1)
   kapak: kapali = kenar -5 deg, acik = kenar +40 deg
   zorunlu pozlar:  yaw   pitch  kapak  | cakisma | eklem disi min bosluk | en yakin cift
                   -25.0 -20.0  open   |       0 |      0.400 | frame_L x lid_L
                   -25.0   0.0  open   |       0 |      0.400 | frame_L x lid_L
                   -25.0  20.0  open   |       0 |      0.400 | coupler x scr_horn_yaw1
                     0.0 -20.0  open   |       0 |      0.400 | frame_L x lid_L
                     0.0   0.0  open   |       0 |      0.400 | frame_L x lid_L
                     0.0  20.0  open   |       0 |      0.400 | frame_L x lid_L
                    25.0 -20.0  open   |       0 |      0.400 | frame_L x lid_L
                    25.0   0.0  open   |       0 |      0.400 | frame_L x lid_L
                    25.0  20.0  open   |       0 |      0.400 | coupler x scr_horn_yaw0
                   -25.0 -20.0  closed |       0 |      0.400 | frame_L x lid_L
                   -25.0   0.0  closed |       0 |      0.400 | frame_L x lid_L
                   -25.0  20.0  closed |       0 |      0.400 | coupler x scr_horn_yaw1
                     0.0 -20.0  closed |       0 |      0.400 | frame_L x lid_L
                     0.0   0.0  closed |       0 |      0.400 | frame_L x lid_L
                     0.0  20.0  closed |       0 |      0.400 | frame_L x lid_L
                    25.0 -20.0  closed |       0 |      0.400 | frame_L x lid_L
                    25.0   0.0  closed |       0 |      0.400 | frame_L x lid_L
                    25.0  20.0  closed |       0 |      0.400 | coupler x scr_horn_yaw0
   ara tarama: cakisma 0; eklem disi en kucuk bosluk 0.400 mm

   TOPLAM CAKISMA (>= 0.01 mm3): 0
4a) EKLEM DISI CIFTLERDE EN DAR 20 BOSLUK (asil carpisma payi):
     0.400  coupler x scr_horn_yaw0   @ yaw 25.0 pitch 20.0 kapak open
     0.400  coupler x scr_horn_yaw1   @ yaw -25.0 pitch 20.0 kapak open
     0.400  frame_L x lid_L   @ yaw -25.0 pitch -20.0 kapak open
     0.400  frame_R x lid_R   @ yaw -25.0 pitch -20.0 kapak open
     0.402  eye_L x scr_fpivot   @ yaw 25.0 pitch 0.0 kapak open
     0.688  scr_ptop_R x lid_R   @ yaw -25 pitch -10 kapak 0.0
     0.688  scr_ptop_L x lid_L   @ yaw -25 pitch -10 kapak 0.0
     0.700  scr_lock_L x frame_L   @ yaw -25 pitch -10 kapak 0.0
     0.700  scr_lock_R x frame_R   @ yaw -25 pitch -10 kapak 0.0
     0.900  frame_L x horn_yaw   @ yaw -25 pitch -10 kapak 0.0
     0.900  frame_R x horn_yaw   @ yaw -25 pitch -10 kapak 0.0
     1.000  eye_L x servo_lid   @ yaw 0.0 pitch -20.0 kapak open
     1.000  frame_L x scr_horn_yaw0   @ yaw 0.0 pitch -20.0 kapak open
     1.000  frame_R x scr_horn_yaw1   @ yaw 0.0 pitch -20.0 kapak open
     1.300  scr_ltip_L x frame_L   @ yaw 0 pitch -10 kapak 0.0
     1.300  scr_ltip_R x frame_R   @ yaw 0 pitch -10 kapak 0.0
     1.600  scr_ym_L40 x horn_yaw   @ yaw 0 pitch -10 kapak 0.0
     1.600  scr_ym_R40 x horn_yaw   @ yaw -12.5 pitch -10 kapak 0.0
     1.785  yaw_mount x lid_carrier   @ yaw -25.0 pitch -20.0 kapak open
     1.859  servo_yaw x yaw_crank   @ yaw 0 pitch -10 kapak 0.0
4b) EKLEM CIFTLERI (tasarim geregi temas / AXIAL_GAP; en dar 12):
     0.000  scr_ltip_L x coupler
     0.000  scr_ltip_R x coupler
     0.000  scr_fpivot x pivot_bracket
     0.000  servo_pitch x horn_pitch
     0.000  servo_yaw x horn_yaw
     0.000  scr_ctip x coupler
     0.000  servo_lid x horn_lid
     0.200  eye_L x scr_ptop_L
     0.200  eye_R x scr_ptop_R
     0.384  eye_R x frame_R
     0.384  eye_L x frame_L
     0.400  eye_lever_L x coupler

5) ET KALINLIGI (isin yontemi; min / %1 / %5, mm) - hedef >= 1.6:
   eye            min  4.61  %1  7.00  %5  8.88  (en ince ~ [-47.6  -6.2   2.1])
   eye_lever      min  2.75  %1  2.75  %5  2.75  (en ince ~ [-47.9 -16.2 -21.7])
   frame_L        min  2.15  %1  2.39  %5  5.00  (en ince ~ [-14.5 -10.1 -25.2])
   frame_R        min  2.15  %1  2.40  %5  5.00  (en ince ~ [ 14.4 -11.  -44. ])
   yaw_mount      min  1.00  %1  1.90  %5  2.86  (en ince ~ [ -0.1   2.6 -35. ])
   yaw_crank      min  2.70  %1  2.75  %5  2.75  (en ince ~ [  6.2 -14.2 -42. ])
   coupler        min  2.35  %1  2.35  %5  2.35  (en ince ~ [ -1.9 -18.4 -63.1])
   lid_carrier    min  1.75  %1  1.93  %5  3.50  (en ince ~ [32.2 22.7 -8.5])
   lid_L          min  1.74  %1  1.99  %5  2.00  (en ince ~ [-38.9  21.    3.8])
   lid_R          min  1.79  %1  1.99  %5  2.00  (en ince ~ [38.6 20.9 -4.4])
   pivot_bracket  min  2.25  %1  2.52  %5  4.60  (en ince ~ [-85.  -48.7  -0. ])
   base           min  0.94  %1  3.15  %5  4.00  (en ince ~ [-14.1   6.1  -3.2])

6) BASKIDA YATAY DELIKLER (+0.2 mm pay verildi; DECISIONS.md):
   frame_L        ust pim pilotu (Y), alt pim pilotu (Y), 2x yaw_mount pilotu (Y)
   frame_R        ust pim pilotu (Y), alt pim pilotu (Y), 2x yaw_mount pilotu (Y)
   lid_carrier    4x kapak vidasi RUN (X), 2x kol vidasi + orta delik (X)
   pivot_bracket  sol pitch yatagi M4_RUN (X)
   base           4x servo kulagi M3 pilot (X)

7) STL / BASKI YONU KONTROLU (out/stl/*.stl oldugu gibi okunur)
   (1) tek bagli govde  (2) min z = 0, 0.2 mm katmanlarda havada baslayan ada yok  (3) >45 deg sarkma alani
   base.stl               govde 1  zmin  0.000  havada ada  0   sarkma  144.4 mm2  tabla  9295.9 mm2  boyut [181.  52.  70.]  OK
   coupler.stl            govde 1  zmin  0.000  havada ada  0   sarkma    0.0 mm2  tabla  1231.0 mm2  boyut [104.   51.    3.5]  OK
   eye.stl                govde 1  zmin  0.000  havada ada  0   sarkma   24.1 mm2  tabla   437.0 mm2  boyut [36. 28. 26.]  OK
   eye_lever.stl          govde 1  zmin  0.000  havada ada  0   sarkma    0.0 mm2  tabla   333.1 mm2  boyut [13.  39.2  3.5]  OK
   frame_L.stl            govde 1  zmin  0.000  havada ada  0   sarkma   87.0 mm2  tabla  1434.6 mm2  boyut [62.4 48.  70.8]  OK
   frame_R.stl            govde 1  zmin  0.000  havada ada  0   sarkma   87.2 mm2  tabla  1404.4 mm2  boyut [62.4 48.  70.8]  OK
   lid_L.stl              govde 1  zmin  0.000  havada ada  0   sarkma   19.2 mm2  tabla   238.1 mm2  boyut [34.3 29.  30. ]  OK
   lid_R.stl              govde 1  zmin  0.000  havada ada  0   sarkma   19.3 mm2  tabla   238.1 mm2  boyut [34.3 29.  30. ]  OK
   lid_carrier.stl        govde 1  zmin  0.000  havada ada  0   sarkma   82.1 mm2  tabla   587.0 mm2  boyut [65. 18. 44.]  OK
   pivot_bracket.stl      govde 1  zmin  0.000  havada ada  0   sarkma   16.0 mm2  tabla   413.4 mm2  boyut [22. 20. 58.]  OK
   yaw_crank.stl          govde 1  zmin  0.000  havada ada  0   sarkma    0.0 mm2  tabla   391.2 mm2  boyut [33.  32.5  3.5]  OK
   yaw_mount.stl          govde 1  zmin  0.000  havada ada  0   sarkma   34.9 mm2  tabla  1050.4 mm2  boyut [39. 44.  9.]  OK
   STL SONUC: hepsi OK

8) VIDA SAYILARI (montaj kaydindan):
     6  M3x10 yuvarlak
     8  M4x10 yuvarlak
    12  M4x16 havsa
     3  SG90
     6  SG90 kol vidasi (servo ile gelir)
     3  SG90 kolu (cift)
   M3 toplam 6 (sinir 14) -> OK

9) SERVO ACILARI (derece):
   yaw    0 pitch    0 kapak closed: EYE_YAW   90.0  EYE_PITCH   90.0  LIDS  112.5
   yaw  -25 pitch    0 kapak closed: EYE_YAW  115.0  EYE_PITCH   90.0  LIDS  112.5
   yaw   25 pitch    0 kapak closed: EYE_YAW   65.0  EYE_PITCH   90.0  LIDS  112.5
   yaw    0 pitch  -20 kapak closed: EYE_YAW   90.0  EYE_PITCH   70.0  LIDS  112.5
   yaw    0 pitch   20 kapak closed: EYE_YAW   90.0  EYE_PITCH  110.0  LIDS  112.5
   yaw    0 pitch    0 kapak open  : EYE_YAW   90.0  EYE_PITCH   90.0  LIDS   67.5
   yaw    0 pitch    0 kapak 0.5   : EYE_YAW   90.0  EYE_PITCH   90.0  LIDS   90.0

SONUC: cakisma 0, eklem disi en kucuk bosluk 0.400 mm (coupler x scr_horn_yaw0 @ (25.0, 20.0, 'open')), gecersiz kati 0, 1.6 alti et (%1) yok, STL hatasi yok, M3 6/14
sure 83 s

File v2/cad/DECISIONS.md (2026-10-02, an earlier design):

# Project Eye v2 — Mekanik kararlar ve şartnameden sapmalar

Bu dosya yalnızca **mekanik iş kolunun** kararlarını içerir (`cad/`). Etiketler: **[SPEC]** şartnameye uygun,
**[SAPMA]** şartnameden ayrılır (gerekçeli), **[SEÇİM]** şartnamenin serbest bıraktığı yerde verilen karar,
**[DOĞRULANMADI]** yalnızca modelde/hesapta var, fiziksel olarak denenmedi.

Tüm sayılar `params.py`'dedir; buradaki değerler oradan kopyadır. Doğrulama: `check.py` → `out/check_report.txt`.

## 1. Genel mimari

| Eksen | Mekanizma | Neden |
|---|---|---|
| Göz yaw (kanal 0) | Kardan **göbeğine** üstten sıkılan tüp+kol; iki göz kolu + ortadaki servo kolu (hepsi r=10, eksenleri z=0 doğrusunda) tek çubukla **paralelkenar** | Göbek yalnızca yaw yapar → yaw = servo açısı, **birebir** ve pitch'ten tamamen bağımsız. İlk denemede (gözün arkasındaki topa itme çubuğu) pitch ±25'te yaw servosu ~10° kayıyordu. |
| Göz pitch (kanal 1) | Gözün **alt kutbundaki** top (yaw ekseni üzerinde) → basılı çubuk → ortak sallanan mil (rocker) → sol servo, mil eş eksenli | Top yaw ekseninde olduğundan pitch=0'da yaw hiç etkilemez. İki göz aynı geometri → sağ/sol pitch eşit. |
| Kapaklar (kanal 2–5) | Her kapak kendi 4-çubuk mekanizması (kapak kolu 12 → bağlantı kolu → servo kolu 10), servolar arka kirişin arkasında | Bağımsız kapaklar (SPEC §4); nötrde kol ve servo kolu bağlantıya dik (ölü nokta kuralı). |

## 2. Şartnameden sapmalar [SAPMA]

1. **Göz çatalı köprüsü** v1'de z=4.5–6.5 idi; pitch ±25'te göbeğin köşesi (4,4) z=5.32'ye süpürüyor → köprü **z=5.7–7.9**'a alındı, ön yüzde ±1.3'e pahlandı; kollar z>2.5'te ±2'ye daraltıldı. (SPEC'in sabit olarak verdiği göbek 8, M2×5, kol 2 mm, boşluk 0.5 aynen korundu.)
2. **Sabit çatal**: kollar ±3 yerine **±4.2** (üst kolda yaw tüpü için Ø4.85 yatak); köprü z=−8…−6 (v1 −9…−7'ye yakın); **direk Ø4 yuvarlak** (v1: Ø5). Köşe pozunda (yaw 30 + pitch 25) direk yönü göze göre 38.3° sapıyor; Ø4 direk + 52° arka açıklık 2.6° pay bırakıyor. Ø5 ile açıklığın ~54°'ye çıkması gerekiyordu, bu da alt pad'in kapak bandına girmesine yol açıyordu.
3. **Bebek Ø3.8** (SPEC Ø4): bebek, göz çatalını kabuğa tutturan **siyah M2 havşa başlı vidanın başıdır** (DIN 965, baş Ø3.8). İris (Ø12) modelde yalnızca görsel gövde; boya/çıkartma ile yapılır.
4. **Vida sabitleme şeması** v1'den farklı: M2 vidalar **çatal kollarına** kılavuzsuz vidalanır, göbek delikleri **geçiş** (Ø2.2) — göbek vida uçları üzerinde döner. v1 çiziminde hangisinin döndüğü belirsizdi.
5. **Göz kabuğunda erişim delikleri** (Ø4.4): iki yanda (yatay kardan vidaları) ve altta (sabit çatalın alt vidası). Montajda göbek kabuğun içinde vidalanmak zorunda; bu delikler olmadan kardan kurulamaz. Yan delikler uç yaw'da pencereden görülebilir → isterseniz boya/tapa.
6. **Kabuk üst yarığı**: yaw tüpü (Ø4.6) kabuğun tepesinden çıkar; kabukta pitch ±25 boyunca 5.8 mm genişlikte yarık var. Göz −25 aşağı bakarken yarığın ön kenarı dünya açısında ~+26°'ye gelir: üst kapak nominal açıkken (kenar +22) örtülür; üst kapak **tam açık + aşağı bakış** kombinasyonunda yarık görünebilir. [DOĞRULANMADI: görsel]
7. **Pitch çubuğu basılı**, uçlarında geçmeli küresel yuva (ağız yarı açısı 61°, top Ø4.8 metal RC rotil topu). Hazır RC rotillerin açılma açısı bilinmediği için yuva geometrisi bizde. Göz ucunda gereken eğim en fazla **20.8°**, yuvanın izni ~31°.

## 3. Serbest bırakılan yerlerde seçimler [SEÇİM]

- **Kapak genişlikleri**: üst 38°, alt 30°. Kapanma: kenarlar −5°'te buluşur, aralarında 1.5° (~0.35 mm) boşluk (sürtünme yok). Mekanik tam açık: üst kenar +38, alt kenar −45 (nominal açık +22/−28 + bakış takibi 0.6×25 payı). Üst kapak dilimi tam açıkta 76°'ye çıkar; yaw tüpü 90°±10°'de → 4° pay. Alt kapak dilimi −75°'e kadar iner; alt pad'in kapak bandını geçtiği dar şeritle (|x|≤2.5) köşe pozunda 3.6° pay.
- **Kapak dilimi kutuplarda koniyle kesilir** (düz kesim ince bıçak kenarı bırakıyordu). Göbekler eksenel yığın: alt kapak 13–15, üst kapak 18.4–20.4 mm (göz merkezinden), kanat (sabit pim taşıyıcı) 20.8–24.8. Kollar yalnız dış tarafta.
- **Alt pad + kanca kabukla tek parça** (kabuk kenar düzlemi tablada basılır; kanca paddan dik yükselir). Pad çerçevesinin kapak bandını (r 12.6–13.8) geçen kısmı yalnızca |x|≤2.5 şerit: yaw+pitch birleşince x≠0 noktaları öne döner ve alt kapağa girer. r≥14.5'teki kısımlar hiçbir pozda kapak kabuğuna giremez (dönme r'yi korur).
- **Gözler ve pitch kolları aynalı**: pad çerçevesinin geniş kısmı her gözde **iç tarafta** (dış tarafta kapak kolları/bağlantıları var; uç pozlarda çerçeve u≈19 mm'ye savruluyor). Sağ rocker kolu dış tarafta. Top x=0'da olduğundan kinematik değişmez.
- **Pitch çubuğu nötrde arkaya doğru 12° yükselir**, rocker kolu 16 mm: yaw×pitch ızgarasında sayısal tarama; göz ucu rotil eğimini 37° → 20.8°'ye indirir, servo −31…+32°.
- **Kapak servoları z=−48.5'te** (arka kirişin arkasında), milleri dışa bakar, iki servo tek tutucu plakada (üst kapak servosunun kulakları yükseltilmiş pedlerde).
- **Maske** z=16.5–19.5, göz pencereleri 27×14 elips. Göz yukarı bakınca pitch kancası z≈15.2'ye gelir.
- **Servo kolu delik yarıçapı r=10** (v1'de kullanılan; SPEC: delik aralığı 2 mm). Stok kolların bu deliği Ø1.6'ya büyütülüp M2 vidalanır.

## 4. Çapraz etki ve firmware sınırları (yazılım tarafı için önemli)

- **Yaw**: çapraz etki yok.
- **Pitch**: pitch=0'da yaw etkisi sıfır; köşelerde var. Yazılım yaw=0 tablosuyla (−25 → servo 56.7) sürerse, yaw ±30'da göz **−31.8°**'ye gider. O bölge doğrulanmadı ve orada yarık/direk çakışması var.
- Bu yüzden **firmware'in sabit pitch sınırı** yaw'dan bağımsız güvenli olacak şekilde önerildi: servo **63.2…121.6°** (her yaw'da göz ±25 içinde; yaw=0'da ulaşılan −20.3…+23.0). Tam ±25 isteyen yazılım `kinematics.json → cross_coupling.EYE_PITCH_servo_deg_grid` ile yaw'a bağlı sınır uygulamalı. `check.py` bu güvenli sınırları yaw ızgarasıyla da tarar.
- SPEC §6'nın doğrusal pitch modeli yaklaşık: +25 → 125.6, −25 → 56.7 (asimetrik). Tablo daha doğru.

## 5. Doğrulama yöntemi ve sınırları

- Çarpışma: CadQuery katıları 0.01 mm sapmayla üçgenlenir; kesişim hacmi manifold3d boolean, mesafe python-fcl. Eşik 0.01 mm³.
- Vidalar kök çapında (Ø1.6) modellendi: diş plastiğe gömülür. Pim Ø1.95 (sıkı geçme deliğiyle eş).
- Eklem çiftleri (pim-göbek, vida-link, kol-mil, top-yuva, tüp-yatak) tasarım gereği 0–0.15 mm boşlukla temas eder. Raporda **eklem dışı** en küçük boşluk ayrıca verilir.
- Et kalınlığı ışın yöntemiyle örneklenir (kenar/köşe örnekleri ayıklanır); 1 %'lik değer raporlanır.
- **Doğrulanmayanlar**: baskı ve montaj toleransları (tolerans test parçası sonrası `params.py [TOL]` güncellenecek), SG90'ın datasheet dışı ölçüleri (kubbe yarıçapı, mil yüksekliği, kulak kalınlığı, delik aralığı 27.8 — varsayım), servo kolu ölçüleri, basılı yuvanın geçme kuvveti, servo torku yeterliliği (hesaplanmadı), dişli boşluğu, sürtünme, esneme. Model rijit ve boşluksuz eklemlidir.

## 6. Dosyalar

- `params.py` tüm ölçüler · `kin.py` kinematik (numpy) · `eye_v2.py` parçalar + montaj + dışa aktarım · `check.py` tarama · `kinematics_export.py` → `out/kinematics.json` · `render.py` → `out/renders/`
- `kin.py`, `kinematics_export.py`, `render.py` SPEC §7 listesinde yok; `eye_v2.py`'yi sade tutmak için ayrıldı.

## 7. Tolerans sabitleri (`params.py` §1 ve ilgili yerler) — test baskısından sonra güncellenecek

Hepsi adlandırılmış sabit; `eye_v2.py`/`check.py` içinde gömülü tolerans yok (kalan ±0.1 değerleri yalnızca boolean kesim payı).
`M2_PILOT 1.7` · `M2_CLEAR 2.2` · `PIN_PRESS 1.95` · `PIN_RUN 2.25` · `AXIAL_GAP 0.4` · `SERVO_POCKET_CLR 0.3` ·
`CBORE_D 4.2` · `CSK_CLR 0.15` · `GLUE_GAP 0.05` · `YAW_COUPLER_HOLE 2.3` · `HORN_SCREW_PILOT 1.6` ·
`SOCKET_CAV_CLR 0.1` · `YAW_TUBE_BEARING_CLR 0.25` (→ `YAW_TUBE_BEARING`) · `YAW_SLOT_CLR 0.6` · `SCREW_HEAD_GAP 0.2`.
Kaldırılan: `NUT_POCKET`, `NUT_M2_*` (tasarımda somun kalmadı). Kapak yığını (`LID_*_U`) ve `YAW_COUPLER_Y` artık
`AXIAL_GAP`'ten türetiliyor. Bir tolerans değişince: `python eye_v2.py && python check.py && python render.py`.

## 8. Doğrulama özeti (son çalıştırma, `out/check_report.txt`)

- 18 zorunlu + 12 firmware-sınır + 87 ara poz = 117 poz: **kesişim ≥ 0.01 mm³ olan çift: 0**.
- Eklem dışı en küçük boşluk **0.173 mm** (göz çatalı ↔ sabit çatal, yaw ±30 + pitch −25 köşesi). Bu, baskı toleransı
  mertebesinde; ilk montajda köşe pozunda sürtünme olup olmadığına bakın. Sonrakiler: kapak↔kapak 0.18 (kapalı), kabuk↔direk 0.29.
- Geçersiz katı: 0; basılan parçaların hepsi tek katı. Et kalınlığı %1 yüzdelik ≥ 1.2 (lokal minimumlar havşa/pah kenarı).

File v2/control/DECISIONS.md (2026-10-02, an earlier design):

# Project Eye v2 — Elektronik/Yazılım kararları

SPEC.md §4–§8 SABİT sözleşmesine uyuldu. Aşağıdakiler şartnamenin açık bıraktığı
yerlerde verilen kararlar ve (varsa) küçük sapmalardır.

## Protokol yorumları (§5)

| Konu | Karar | Gerekçe |
|---|---|---|
| `?` cevabı | Yalnızca `STATE ...` döner, ayrıca `OK` gönderilmez. | STATE zaten onaydır; PC tarafında satır eşleştirmesi basit kalır. |
| `STATE` açıları | **Anlık** (hız sınırlı) konum, 1 ondalık. | Hedef değil, servonun o an nerede olduğu daha faydalı. |
| `idle=<0\|1>` | Firmware'in **şu an** canlı modda olup olmadığı (A bayrağı değil). | PC'nin "kontrol kimde" sorusuna doğrudan cevap. |
| Idle sayacı | Yalnızca `S` sıfırlar. `?` ve `A` sıfırlamaz. | Sadece durum soran bir PC gözleri dondurmasın; SPEC "ilk S'de kontrol PC'ye geçer" diyor. |
| `D` sonrası | Servolar bırakılır ve bir sonraki `S`'e kadar idle **başlamaz**. | `D` güvenlik komutudur; 2 sn sonra servoların kendiliğinden canlanması sürpriz olurdu. |
| 0–180 dışı açı | `ERR angle out of 0-180`, satır uygulanmaz. 0–180 içi değerler sessizce mekanik limite kırpılır (`OK`). | §5 "0–180" diyor; aralık dışı değer büyük olasılıkla bozuk veri. |
| Esneklik | `\r` yok sayılır, boşluk/tab ayırıcı, boş satır sessizce yok sayılır, komut harfi küçük de olabilir. | Seri monitörden elle deneme kolaylığı. PC her zaman büyük harf gönderir. |
| Bozuk satır | >64 karakterlik satır sonuna kadar atılır, tek `ERR line too long`; yazdırılamaz bayt → `ERR bad character`. | Tampon asla taşmaz, bir sonraki satırda toparlanır. |

## Firmware

- **Mekanik limitler = `cad/out/kinematics.json → limits_checked`, pay yok** (ilk sürümdeki
  geniş 45–135 / 30–150 zarfı kaldırıldı; o bölge çakışma taramasından geçmemişti):

  | Kanal | Min | Max | Kaynak |
  |---|---|---|---|
  | EYE_YAW | 60.00 | 120.00 | limits_checked (servo = 90 + yaw, pitch'ten bağımsız) |
  | EYE_PITCH | 63.17 | 121.62 | `EYE_PITCH_firmware_safe` (yaw'dan bağımsız güvenli) |
  | LID_UL / LID_UR | 64.38 / 64.37 | 115.63 / 115.62 | limits_checked |
  | LID_LL / LID_LR | 66.23 | 113.77 | limits_checked |

  **Pitch bedeli:** sabit sınır her yaw'da güvenli olmak zorunda; yaw ±30'da tam ±25'i
  verir ama yaw=0'da göz yalnızca **−20.3…+23.0°**'ye ulaşır. Yaw=0 tablosunun
  56.73–125.59 aralığı kullanılsaydı yaw ±30'da göz −31.8°'ye gidip yarık/direk
  çakışmasına girerdi. Yaw'a bağlı firmware sınırı (her iki servonun anlık konumuna
  bakan) daha geniş aralık verirdi, ama iki servo bağımsız hızlarla hareket ederken
  geçişlerde güvenlik garantisi zorlaşır; bu yüzden orkestratörün istediği sabit sınır uygulandı.
  Limitler 2 ondalıklı olduğundan PC `S` açılarını **2 ondalıkla** gönderir
  (1 ondalıkta 113.77 → 113.8 limit dışına yuvarlanıyordu).
- **Idle kalibrasyonu derleme zamanında:** firmware PC'siz yaşarken kapak açık/kapalı
  açılarını bilmek zorunda. Protokol SABİT olduğu için kalibrasyon yükleme komutu
  eklenmedi; `IDLE_LID_CLOSED/OPEN`, `IDLE_EYE_*` settings.json ile aynı (şu an
  kinematics.json önerisi; pitch idle'da doğrusal 34.43°/birim, ±0.45 birim → ±15.5°,
  sınırların içinde). Kalibrasyondan sonra elle güncellenmeli; `test_firmware_sync`
  settings.json ile farkı yakalar.
- Hız sınırı 600°/s, 5 ms tik, `millis()` tabanlı, bloklamaz. Alt-derece çözünürlük için
  `writeMicroseconds` (544–2400 µs = Servo.h varsayılanı) kullanılır.
- Açılışta gözler 90°, kapaklar %80 açık konuma **hız sınırı olmadan** gider (servo
  konumu bilinmez, kaçınılmaz). Darbe genişliği `attach`'tan önce yazılır ki servolar 90°'ye zıplamasın.
- Idle: %30 olasılıkla merkeze yakın, aksi halde ±0.6 / ±0.45 birim rastgele sakkad
  (0.4–2.5 sn aralık); 3–6 sn'de bir 120 ms kırpma; 5 sn periyotlu kapak nefesi
  (0.72 ± 0.12); kapaklar PC ile aynı formülle pitch'i takip eder.

## PC yazılımı

- **Kapaklarda `invert`:** §6 kapak formülü `invert`'i kullanmıyor ama şemada var.
  Anlamı: servo ayna takıldıysa ham açı `180 − açı` olarak aynalanır; `closed/open`
  mantıksal değer olarak kalır. calibrate.py bunu hesaba katarak kaydeder.
- **Kapak–pitch takibi:** `shift = lid_follow_pitch · 0.5 · v · aciklik`;
  üst = açıklık + shift, alt = açıklık − shift (0..1'e kırpılır). Açıklıkla orantılı
  olduğundan kapalı göz bakış yüzünden aralanmaz. Firmware idle'ı aynı formülü kullanır.
- **Sakkad hız sınırı** derece uzayında (yaw ve pitch birlikte, vektör uzunluğu ≤
  `saccade_speed_deg_s`·dt). Firmware'in 600°/s sınırı bunun üstünde ikinci emniyet.
- **Kırpma şekli:** Lunar ultimatum'daki 0.16 sn üçgen yerine 0.25 sn yamuk
  (kapan %30, kapalı %20, açıl %50). 600°/s'de ~60° kapak yolu ~100 ms sürdüğü için
  0.16 sn'lik kırpmada kapak fiziksel olarak tam kapanamazdı.
- **İki idle katmanı:** `behaviour.idle_after_s` (1.5 sn) PC tarafı "bakacak kimse yok →
  yavaş gezin" eşiğidir; bu sırada PC keepalive S göndermeye devam eder (0.5 sn'de bir),
  firmware idle'ına geçilmez. Firmware idle'ı yalnızca PC `release()`/`close()` ettiğinde
  ya da bağlantı koptuğunda devreye girer. `close()` varsayılan olarak `A 1` gönderir
  (program kapanınca göz kendi başına yaşamaya devam eder); `close(detach=True)` servoları bırakır.
- **S gönderimi:** en fazla 50 Hz, yalnızca ≥0.1° değişimde, 2 ondalık (satır ≤ 47 bayt).
  `compute_angles` her açıyı firmware limitine kırpar; calibrate.py'nin jog'u da limitte durur —
  PC hiçbir yolda limit dışı açı göndermez.
- **Kinematik tablolar (`cad/out/kinematics.json`):** varsa `EyeController` otomatik yükler
  (`eye.mapping == "TABLE"`), yoksa/bozuksa SPEC §6 doğrusal formülüne düşer (`"LINEAR"`), çökmez.
  - Göz: `u,v` → göz açısı yaw = u·30°, pitch = v·25° (tablo kapsamı; bu modda `deg_per_unit`
    kullanılmaz, yalnızca doğrusal yedekte). Yaw servosu 1B tablodan, pitch servosu
    `cross_coupling.EYE_PITCH_servo_deg_grid`'den **çift doğrusal enterpolasyonla** (köşe çapraz
    etkisi telafi edilir). `center` = kalibrasyon trimi (tablo notrundan kayma), `invert` =
    servo tepkisini center etrafında aynalar. Sonra settings `[min,max]` ve firmware limiti:
    ulaşılamayan poz (ör. yaw=0'da pitch −25) en yakın güvenli poza iner.
  - Kapak: 4-çubuk tablosu T(o) kalibrasyona oturtulur:
    `angle = closed + (T(o) − T(0))·(open − closed)/(T(1) − T(0))` — o=0/1'de kalibre edilen
    değer aynen korunur, eğri modelden gelir. Pitch takibinde açıklık tablonun payına kadar
    (üst 1.61, alt 1.76) 1'in üstüne çıkabilir; doğrusal modda 1'de kalır.
  - settings.json şeması **değişmedi**; değerler `settings_suggestion`'dan alındı (EYE_PITCH
    `_note` alanı alınmadı). `DEFAULT_SETTINGS` (eksik anahtar tamamlama) de aynı öneriye çekildi,
    çünkü SPEC §6 örnek kapak değerleri (60/120 …) yeni limitlerin dışında kalıyordu.
- **Port bulma:** Arduino/CH340 benzeri portlar önce, Bluetooth sanal portları atlanır.
  Her aday açılır ve `EYE v2 READY` beklenir; gelmezse (kart resetlenmediyse) 2 sn sonra
  zararsız `?` gönderilir ve `STATE` beklenir. `READY` gönderen cihaz (Lunar gimbal)
  anında reddedilir; ona hiçbir S/D/A gitmez (test ediliyor).
  **Not:** Bir Uno'nun portunu açmak onu resetler — Lunar gimbal'i kullanılmıyorken
  tarama onu yeniden başlatabilir (zararsız, merkeze döner). Bunu tamamen önlemek için
  settings.json'da `serial_port: "COMx"` ya da `EYE_EXCLUDE_PORTS=COM3` ortam değişkeni.
  Şemaya yeni anahtar eklememek için hariç tutma ortam değişkeniyle yapıldı.
- **Sim'e düşme:** pyserial yoksa ya da cihaz bulunamazsa `sim.SimSerial` (firmware'in
  Python eşdeğeri) kullanılır; üst katmanlar farkı görmez. Çalışırken bağlantı koparsa
  komut gönderimi durur, mod `OFFLINE` olur, program çökmez.
- **face_follow:** Ultimatum'daki momentum/öngörü (MomentumPredictor) taşınmadı; yerine
  gürültü için EMA + hız tabanlı "odak" kısılması kullanıldı. Öngörü gimbal gecikmesini
  telafi ediyordu; burada firmware hızı (600°/s) ve sakkad hızı yeterli görüldü — donanımda
  gecikme hissedilirse geri eklenebilir. Kamera robotla aynı yöne (izleyiciye) bakıyor
  varsayılır: ham karede sağdaki yüz robotun sağındadır (+u); ters ise `--mirror` / `m`.
  Tekil örnek kilidi kendi dosyasıdır (`control/.face_follow.lock`); Lunar aynı kamerayı
  kullanıyorsa kamera açılamaz ve açık bir hata mesajı verilir.
- **Testler `unittest`** (stdlib) ile yazıldı: makinede pytest kurulu değil ve testlerin
  pyserial/mediapipe olmadan da koşması istendi. `pytest` ile de keşfedilir.

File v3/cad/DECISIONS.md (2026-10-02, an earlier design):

# Project Eye v3 (POC) — mekanik kararlar

Etiketler: **[SPEC]** şartnameye uygun · **[SAPMA]** şartnameden ayrılır · **[SEÇİM]** serbest bırakılan yerde verilen karar ·
**[DOĞRULANMADI]** sadece modelde/hesapta var, fiziksel olarak denenmedi. Tüm sayılar `params.py`'de. Doğrulama: `out/check_report.txt`.

## 1. Mimari (v2'den farkı: her bağlantı düzlemsel, 3B mafsal yok)

| Kanal | Mekanizma | Neden |
|---|---|---|
| EYE_PITCH (1) | İki göz ortak bir **pitch çerçevesinde** (frame_L + frame_R + yaw_mount). Çerçeve göz merkezlerinden geçen X ekseninde döner: **sağda pitch servosunun koluna vidalı (direkt)**, solda sabit yatakta M4 pim. | Eksen göz merkezinden geçtiği için pitch = servo açısı (birebir). Lama/rotil yok. |
| EYE_YAW (0) | Her göz çerçevede **dikey M4 pimlerle** (üst + alt) döner. Yaw servosu **çerçevenin üstünde taşınır**; iki göz kolu + servo krankı (r=20) tek düz lamayla paralelkenar. | Servo çerçeveyle birlikte eğildiği için paralelkenar her pitch'te düzlemsel kalır → 3B mafsal gerekmez (SPEC kural 2'nin "eksenleri paralel tut" seçeneği). Kol/krank nötrde lamaya dik (kural 6). |
| LIDS (2) | İki üst kapak aynı X ekseninde; ikisi tek **taşıyıcıya** (lid_carrier) 2'şer M4 ile bağlı. Taşıyıcı ortadaki servonun koluna vidalı (direkt). | Kapak ekseni = göz merkez ekseni → kapak-göz boşluğu her pozda sabit. |

- **Pim şeması [SPEC]:** vida sabit parçanın `M4_PILOT` deliğine vidalanır (kafa havşalı/yüzeyde), dönen parça `M4_RUN` deliğinde döner, arada `AXIAL_GAP` 0.4. Göz pimleri: vida çerçevede, göz döner. Sol pitch pimi: vida çerçeve yan plakasında (çerçeveyle döner), sabit yatakta (`base`) RUN deliğinde döner — kafa yatağın dış yüzüne sürtünür.
- **Direkt sürüş [SEÇİM]:** pitch ve kapaklarda lama yok → lamaya-dik kuralı bu iki kanalda geçersiz, ölü nokta yok. Kapak servosunda 90° = yarı açık (aralık ortada).
- **Parça sayısı:** 12 farklı STL (14 basılı adet): eye ×2, eye_lever ×2, coupler, yaw_crank, frame_L, frame_R, yaw_mount, lid_L, lid_R, lid_carrier, pivot_bracket, base.
- **Sol yatak ayrı parça (pivot_bracket) [SEÇİM]:** çerçevenin sağ yan plakası servo miline eksenel olarak geçirilmek zorunda; sabit bir sol yatak (0.4 boşluk) bunu engellerdi. Yatak çerçeve takıldıktan sonra alttan 2× M4×16 ile base'e vidalanır.

## 2. Şartnameden sapmalar [SAPMA]
1. **Kapak göze 3.3 mm uzakta** (kapak iç küresi R21.3, göz R18). Gözün üst pimini taşıyan çerçeve kolu gözle kapak arasından geçmek zorunda (kol küre kabuğu 18.4–20.8, 2.4 et). Görsel olarak kalın kapak gibi görünür.
2. **Alt kapak yok [SPEC]**, ayrıca **maske/yüz plakası yapılmadı** (zaman). Önden bakınca ortadaki kapak servosu ve direk iki gözün arasında görünüyor.
3. **Gözde düz yüzeyler:** üst/alt y=±13 düzlemleri (pim yüzleri, alt yüzey baskı tablası) ve arka z=−10 kesiği. Önden görünmez; göz tam aşağı bakınca alt düzlemin kenarı görülebilir.
4. **Yaw kolu kilit vidası gözün önünde** (z=+8.5): arkada yer yoktu (pim deliğiyle havşa çakışıyordu). Kol gözün altından ~15 mm öne taşar; maske yoksa alttan görünür.
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

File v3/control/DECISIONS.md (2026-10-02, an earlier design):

# Project Eye v3 (POC) — Elektronik/Yazılım kararları

v3 = v2 yazılımının 3 servoya sadeleştirilmiş hali. v2'nin protokol yorumları ve
güvenlik kuralları (`../../v2/control/DECISIONS.md`) aynen geçerli; burada yalnızca farklar var.

## Kanallar ve protokol
- Kanal 0 `EYE_YAW` D3, 1 `EYE_PITCH` D5, 2 `LIDS` D6 (iki üst kapak tek servoda).
- `S a0 a1 a2` (tam 3 açı; v2'nin 6 açılı satırı `ERR S needs 3 angles`), açılış `EYE v3 READY`,
  `STATE a0 a1 a2 idle=<0|1>`. D / A / ? ve tüm hata kuralları v2 ile aynı.
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

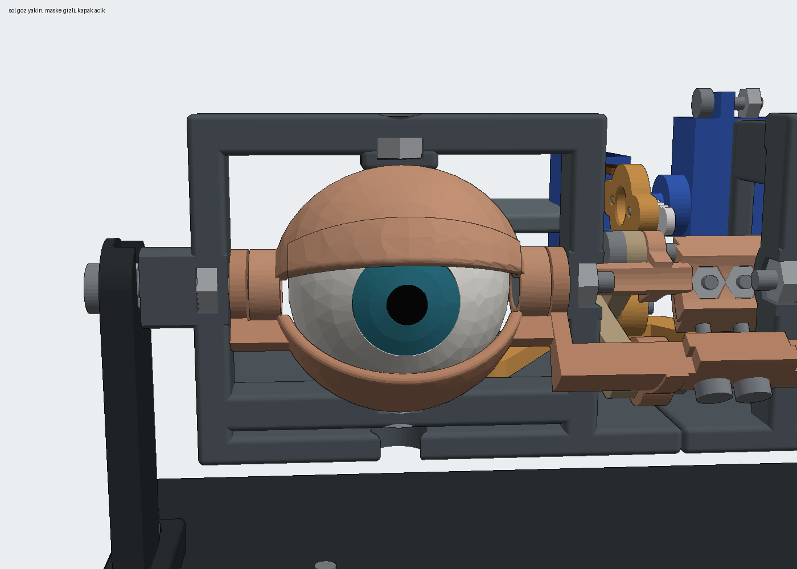
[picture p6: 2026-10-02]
v5/cad/out/renders/06_eye_closeup_open.png

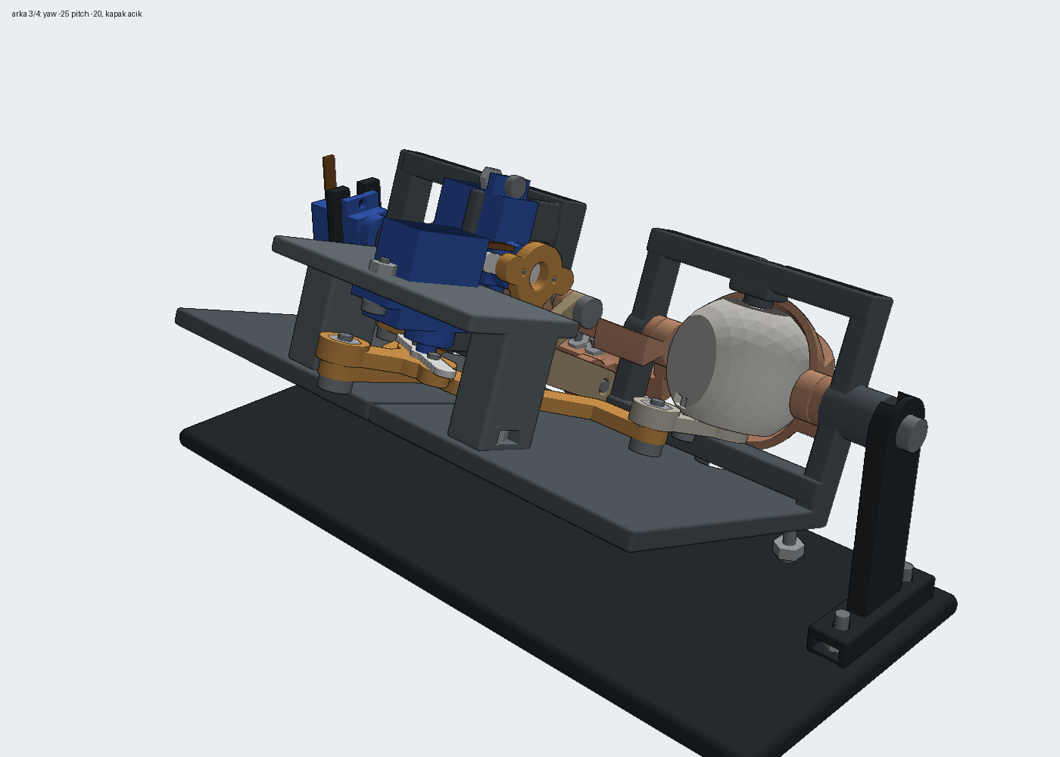
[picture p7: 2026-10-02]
v5/cad/out/renders/08_rear_three_quarter.png

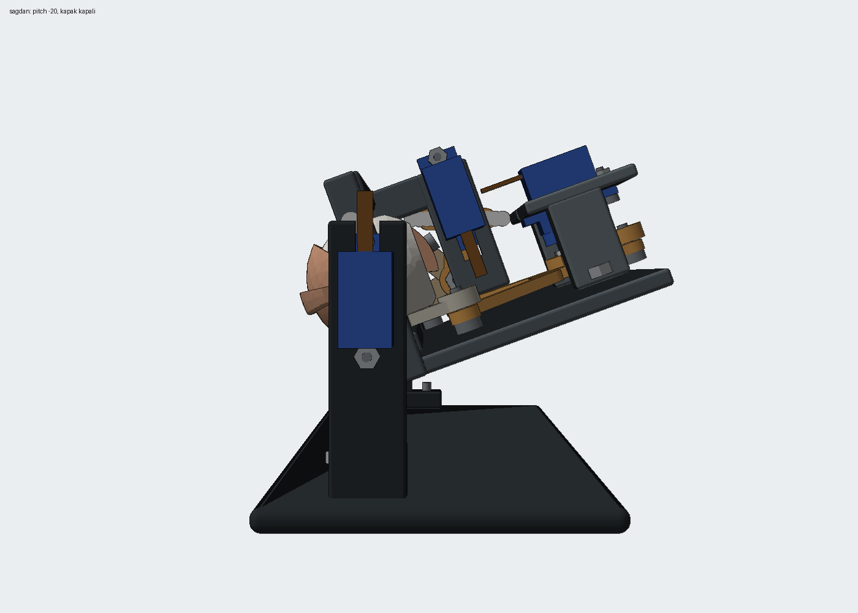
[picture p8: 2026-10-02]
v5/cad/out/renders/09_side_right.png

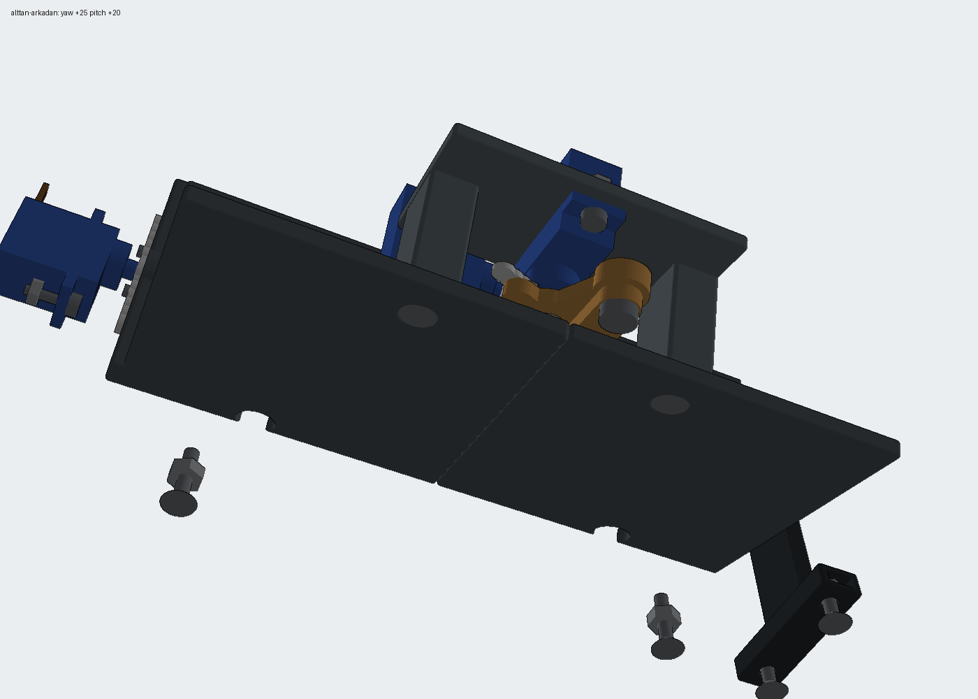
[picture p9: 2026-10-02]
v5/cad/out/renders/11_bottom_rear.png

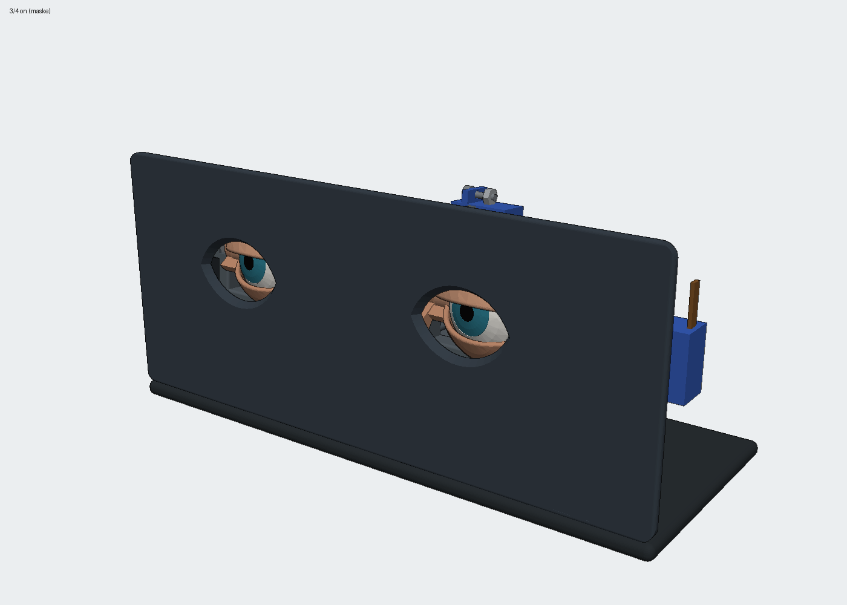
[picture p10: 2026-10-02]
v5/cad/out/renders/04_three_quarter_mask.png

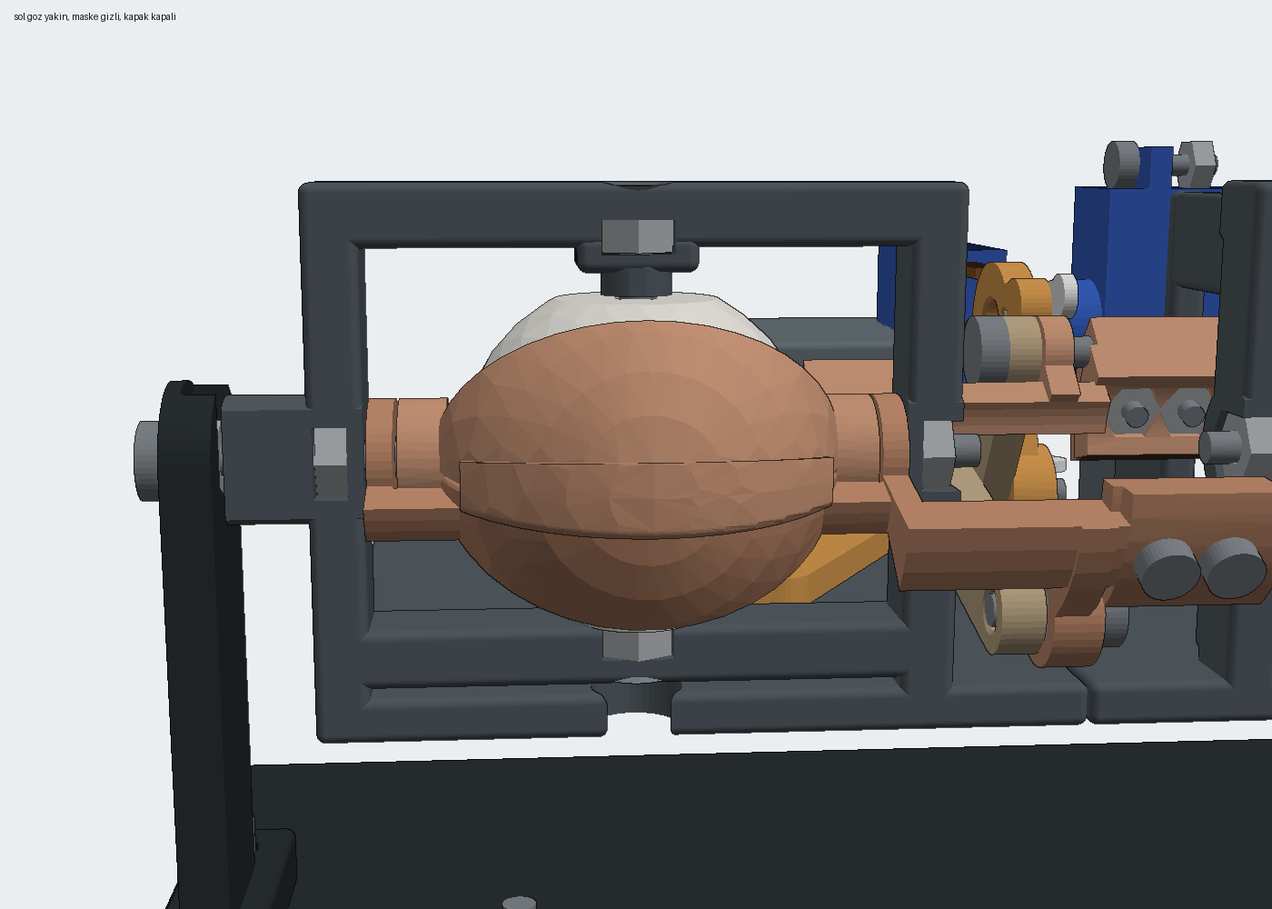
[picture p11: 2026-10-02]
v5/cad/out/renders/07_eye_closeup_closed.png

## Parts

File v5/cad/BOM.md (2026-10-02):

# Project Eye v5 (v4 + somunlu bağlantılar) — malzeme listesi

Sayılar `eye_v5.py` montaj kaydından (`check.py §8`). Ender 3 Neo, 0.4 nozül, PLA, 0.2 mm.
Servo cebi 22.9 × 12.7 (SG_L 22.5 + 0.4, SG_W 12.5 + 0.2). Somun cebi AF + 0.3, derinlik + 0.2 ([TOL], test edilmedi).

## 1. Basılacak parçalar (`out/stl/`) — 16 farklı STL, 19 baskı

| STL | Adet | Boyut (mm) | Baskı yönü | Not |
|---|---|---|---|---|
| `eye` | 2 | 36×32×29 | alt düz yüz tablada | M3 somun cebi (arka düzden kaydırmalı) |
| `eye_lever` | 2 | 13×32×5 | **alt yüz tablada** (v4: üst) | uç göbeğinde üstten açık M4 somun cebi |
| `coupler` | 1 | 104×69×3.5 | düz | |
| `yaw_crank` | **2** | 26×34×5 | alt yüz tablada | biri yaw, biri LIDS krankı; uçta M4 somun cebi |
| `link_up` / `link_lo` | 1+1 | 19×26×3.5 / 37×16×4.5 | düz | |
| `frame_L`, `frame_R` | 1+1 | 88×57×78 / 83×57×78 | ön yüz tablada | somun cepleri ön yüze (tablaya) açık kanal; sarkma 230 / 440 mm² |
| `yaw_mount` | 1 | 69×35×30 | plaka üstü tablada | bacaklarda dışa açık M4 somun kanalı |
| `lid_up_L/R`, `lid_lo_L/R` | 1+1+1+1 | ~40×21×90 … | dış menteşe göbeği tablada | **destek önerilir** (kubbe altı 280–460 mm²), brim |
| `pivot_bracket` | 1 | 11×40×62 | ayak tablada | pitch pimi somunu (üstten kanal), ayakta 2 somun |
| `base` | 1 | **217.5**×89×74 | taban tablada | tablaya sığar (220), kenarlara dikkat |
| `mask` | 1 | **217.5**×92×30 | ön yüz tablada | pedlerde arkadan kanallı M4 somun |

Hepsi tek gövde, havada başlayan ada yok, et %1 ≥ 1.6 (`check.py §5, §7`).

## 2. Vidalar ve somunlar

| Parça | Adet | Nerede |
|---|---|---|
| **M4×16 havşa** | **15** | göz üst pimi 2, alt pimi 2; kapak menteşesi 4 (kafa üst kapak göbeğinin havşasında); LIDS krank ucu 1; yaw_mount ↔ kiriş 2; pivot_bracket ↔ base 2; maske ↔ base 2 |
| **M4×10 yuvarlak** | **6** | göz kolu uçları 2 + yaw krank ucu 1 (lama pimleri); sol pitch pimi 1; kapak lama pimleri 2 (U: plastiğe vidalı, L: somunlu) |
| **M3×10 yuvarlak** | **8 / 14** ✅ | göz kolu kilidi 2; SG90 kulakları 3 (mile UZAK kulak); orta bindirmeler 3 (üst 1, alt 2) |
| **M4 somun** | **20** | yukarıdaki M4'lerin U pimi hariç hepsi |
| **M3 somun** | **8** | bütün M3'ler |
| SG90 küçük vidaları | 6 | servo kolu ↔ basılı parça (servoyla gelir) |

## 3. Montaj sırası
**`../MONTAJ.md`'ye taşındı** (2026-09-30). Eski sıra fiziksel olarak uygulanamıyordu (üst lama pimi, göz kolu ucu vidaları,
bindirme vidası). Yeni sıra `check_montaj.py` ile vida vida denetlenir (her vidanın giriş yolu + tornavida).

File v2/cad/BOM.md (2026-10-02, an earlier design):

# Project Eye v2 — Mekanik malzeme listesi (BOM)

Kaynak etiketleri: **[KAYNAK]** datasheet/standart, **[SEÇİM]** bu tasarımın kararı, **[VARSAYIM]** tedarik edilen
parçada ölçülmeli. Gerekçeler `DECISIONS.md`'de. Sayılar `eye_v2.py` montaj kaydından sayıldı (elle değil).

## 1. Basılacak parçalar (`out/stl/`, baskı yönüne döndürülmüş)

Yazıcı: Ender 3 Neo, 0.4 nozul. Toleranslar henüz **test baskısıyla doğrulanmadı**; `cad/tolerance/` sonucu gelince
`params.py [TOL]` değerleri güncellenip her şey yeniden üretilecek.

| STL | Adet | Malzeme [SEÇİM] | Hacim | Baskı yönü | Destek |
|---|---|---|---|---|---|
| `eye_shell_L`, `eye_shell_R` (aynalı) | 1+1 | PLA beyaz | 2.4 cm³ | kenar düzlemi tablada, ön kutup yukarıda | Hayır. İç kubbe tavanı köprülenir (görünmez yüzey, çatal sapı buraya yapışır) |
| `eye_fork` | 2 | PETG | 0.3 | kollar tablada, sap yukarı | Hayır (9 mm köprü) |
| `gobek` | 2 | PETG | 0.5 | herhangi yüz | Hayır |
| `fixed_fork` | 2 | PETG | 1.3 | flanş tablada | Küçük ağaç destek önerilir (kolların köprüden 1.7 mm taşan altları) |
| `yaw_lever` | 2 | PETG | 0.4 | kol plakası tablada, tüp yukarı | Hayır |
| `lid_upper_L/R`, `lid_lower_L/R` (aynalı) | 1+1+1+1 | PLA ten rengi | 0.5–0.7 | pim ekseni dik, dış göbek tablada | Evet, az (ağaç). ~60–70 mm² sarkma (kubbe dilimi uçları, göbek diski) |
| `lid_link_upper`, `lid_link_lower` | 2+2 | PETG | 0.5 | düz | Hayır |
| `yaw_coupler` | 1 | PETG | 0.8 | düz | Hayır |
| `rocker` | 1 | PETG | 5.5 | düz tarak (kol yüzü tablada) | Hayır |
| `pitch_link_L`, `pitch_link_R` (aynalı) | 1+1 | PETG | 0.5 | göz ucu yuva ağzı aşağı | Evet (ağaç, yuvaların altı). Geçmeli yuva: **deneme gerekir** [DOĞRULANMADI] |
| `back_frame` | 1 | PETG | 16.5 | kiriş arka yüzü tablada | Hayır (raf penceresi ve havşa tavanları köprü) |
| `mount_lid_servos_L/R` | 1+1 | PETG | 5.6 | plaka tablada | Hayır |
| `mount_pitch_servo` | 1 | PETG | 3.0 | plaka tablada | Hayır |
| `rocker_bearing` | 1 | PETG | 1.0 | plaka tablada | Hayır |
| `mask` | 1 | PLA | 25.1 | ön yüz tablada | Hayır |
| `base` | 1 | PETG | 58.3 | alt yüz tablada (158×93) | Hayır (havşa tavanları köprü) |

Toplam ≈ 137 cm³ katı hacim (dolgu hariç). Sarkma alanları `check_report.txt §6`'dan.

**Baskı ayarı önerisi [SEÇİM, doğrulanmadı]:** hareketli ve vidalı parçalar PETG, 0.16–0.2 mm katman, 4 çevre,
%40 gyroid. Göz ve kapaklar 0.12 mm katman (küre yüzeyi için). Küçük delikleri (Ø1.7/Ø2.2) matkap ucuyla
(1.6/2.1) temizleyin.

## 2. Satın alınan parçalar

| Parça | Adet | Nerede | Etiket |
|---|---|---|---|
| SG90 mikro servo | 6 | kanal 0–5 | [KAYNAK] SPEC §4 |
| SG90 tek kollu servo kolu (servoyla gelir) | 5 | 4 kapak + yaw | r=10 deliği **Ø1.6'ya büyütülür** (M2 vida) [VARSAYIM: r=10 deliği var] |
| SG90 çapraz kol (servoyla gelir) + 2 küçük kol vidası | 1 | pitch servosu → rocker flanşı | [VARSAYIM] |
| RC rotil topu, Ø4.8 top, M2 saplama (4 mm diş) | 4 | 2 göz kancası + 2 rocker kolu | [VARSAYIM] top merkezi yakadan 4.9 mm; farklıysa `BALL_H` güncellenir |
| Ø2×12 çelik pim (DIN 7 / ISO 2338 m6) | 4 | kapak pimleri (kanatlara sıkı geçme) | [KAYNAK] standart |

## 3. Vidalar (hepsi M2, ISO 4762 silindir başlı; tek istisna bebek vidası)

| Ölçü | Adet | Kullanım |
|---|---|---|
| M2×4 DIN 965 **siyah havşa başlı** | 2 | göz çatalı sapı → kabuk (vida başı = bebek) |
| M2×4 | 6 | kapak bağlantı kolu eklemleri (4 servo ucu + 2 üst kapak kol ucu) |
| M2×5 | 23 | kardan yatay (4) + sabit çatal alt (2); paralelkenar eklemleri (3); servo kulakları (12); alt kapak kol ucu (2) |
| M2×6 | 12 | tabandan tutuculara (alttan havşalı) |
| M2×8 | 5 | direk flanşları → kiriş (4), rocker yatağı (1) |
| M2×16 | 2 | yaw kolu → göbek (tüp içinden) |
| **Toplam** | **50** | somun yok: tüm vidalar plastiğe kılavuzsuz (Ø1.7) veya geçiş (Ø2.2) |

## 4. Sarf

- Siyanoakrilat yapıştırıcı: göz çatalı sapı ↔ kabuk iç kutbu (vidaya ek, dönmeyi önler)
- Orta güç diş sabitleyici (plastik uyumlu) veya bir damla CA: eklem vidaları (M2×4/M2×5) gevşemesin
- İris boyası/çıkartması (Ø12), isteğe bağlı erişim deliği tapaları/boya
- Kablo, 5 V ≥ 3 A güç kaynağı: elektronik iş kolu (SPEC §4)

## 5. Montaj sırası (kısa)

1. Göz: çatalı kabuğa sok, bebek vidası + CA. Göbeği içeri koy, yan erişim deliklerinden 2×M2×5 (çatal kollarına vidalanır, göbek serbest döner).
2. Sabit çatalı arkadan eğik sok (kafa 8.4×13, açıklık Ø16.4), alt erişim deliğinden M2×5. Yaw kolu tüpünü üst yarıktan göbeğe oturt, M2×16 ile sık.
3. Direk flanşlarını kirişe 2×M2×8 ile (arkadan) bağla.
4. Kapakları önden göze geçir: **önce alt kapak** (iç göbek), sonra üst kapak (kulağı alt göbeğin üstünden geçer). Ø2 pimleri kanatlardan çak. **İç pimler yaw servosundan önce** takılmalı (servo iki iç kanat arasına 0.5 mm boşlukla girer).
5. Servoları orta konuma (90°) al, **sonra** kolları takılacak yönde tak: yaw kolu −Z'ye, kapak kolları kinematics.json nötr açısına (kol bağlantıya dik), rocker kolu yukarı.
6. Paralelkenar çubuğunu 3×M2×5 ile, pitch çubuklarını rotil toplarına bastırarak, kapak bağlantı kollarını M2×4/5 ile bağla.
7. `calibrate.py` ile kanal kanal sınırları bul; başlangıç için `out/kinematics.json → settings_suggestion`.

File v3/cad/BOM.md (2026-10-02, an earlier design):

# Project Eye v3 (POC) — malzeme listesi

Sayılar `eye_v3.py` montaj kaydından (`check.py §8`). Ender 3 Neo, 0.4 nozül, "Epic POC" profili (0.2 mm, destek yok).
Toleranslar tolerans testiyle **henüz doğrulanmadı** → test sonucu `params.py §1`'e girilip her şey yeniden üretilecek.

## 1. Basılacak parçalar (`out/stl/`, baskı yönüne çevrilmiş, tabla z=0)

| STL | Adet | Boyut (mm) | Baskı yönü | Destek / sarkma (check §7) |
|---|---|---|---|---|
| `eye` | 2 | 36×28×26 | alt düz yüz tablada | Yok. 24 mm² = delik tavanları |
| `eye_lever` | 2 | 13×39×3.5 | üst yüz tablada (havşa yukarı) | Yok |
| `coupler` (yaw laması) | 1 | 104×51×3.5 | düz | Yok |
| `yaw_crank` | 1 | 33×33×3.5 | düz | Yok |
| `frame_L`, `frame_R` (aynalı) | 1+1 | 62×48×71 | yan plakanın dış yüzü tablada | **Yok**, ama ~87 mm² sarkma: üst kolun küre kabuğu dış yüzü ~47° (sınırda) + delik tavanları. Üst kolun alt kenarında hafif pürüz olabilir. |
| `yaw_mount` | 1 | 39×44×9 | plaka üst yüzü tablada | Yok (35 mm²: havşa konileri 45°) |
| `lid_L`, `lid_R` (aynalı) | 1+1 | 34×29×30 | kapağın iç uç yüzü (takviye) tablada | Yok (19 mm² = pilot tavanları). Tabla teması küçük (238 mm²): **brim önerilir** |
| `lid_carrier` | 1 | 65×18×44 | üst köprünün üst yüzü tablada | Yok (82 mm²: 45° kenarlı göbek + delik tavanları) |
| `pivot_bracket` (sol pitch yatağı) | 1 | 22×20×58 | ayak tablada | Yok. Yatak deliği yatay (+0.2) |
| `base` | 1 | 181×52×70 | taban tablada | Yok. 160 mm² = servo cebi tavanları (12.7 mm köprü) + kapak servosu penceresinin **30° eğik üst kenarı** (hafif sarkabilir, temizleyin) |

12 farklı STL, 14 baskı. Hepsi tek gövde, havada başlayan ada yok (`check.py §7`).

## 2. Vidalar (eldeki malzeme)

| Vida | Adet | Nerede |
|---|---|---|
| **M4×16 havşa** | **12** | göz üst pimi 2, göz alt pimi 2 (çerçevede sabit, göz döner); göz kolu kilidi 2 (alttan gözün önüne); yaw_mount → arka kiriş 4; base → pivot_bracket 2 (alttan) |
| **M4×10 yuvarlak** | **8** | sol pitch pimi 1 (çerçevede sabit, yatakta döner); lama pimleri 3 (2 göz kolu + krank; kafa lamanın altında); kapak → taşıyıcı 4 |
| **M3×10 yuvarlak** | **6 / 14** ✅ | SG90 kulakları, 3 servo × 2 (kulak delikleri **3.2 mm matkapla** büyütülür) |
| SG90'ın kendi küçük vidaları | 6 | servo kolu ↔ basılı parça (pitch: frame_R, yaw: yaw_crank, kapak: lid_carrier), kolun göbeğe en yakın delikleri. **≤ 5 mm** olmalı (yaw krankında uzun vida lamaya değer) |
| SG90'ın kol merkez vidası | 3 | kolu mile; basılı parçadaki Ø7 delikten sıkılır |

M2 / somun / pim / rotil / tel **kullanılmıyor**.

## 3. Satın alınan / eldeki
- SG90 × 3 (kanal 0 EYE_YAW, 1 EYE_PITCH, 2 LIDS) + her birinin çift kollu kolu.
- Arduino Uno, 5 V ≥ 2 A güç (elektronik kolu).

## 4. Montaj sırası (kısa)
1. SG90 kulak deliklerini 3.2 mm aç. Servoları 90°'ye getir (kol takmadan).
2. **Kollar:** her servo kolunu basılı parçasına (frame_R dış yüzü, yaw_crank, lid_carrier göbeği) servonun küçük vidalarıyla, vida kafaları kolun SERVO tarafında kalacak şekilde vidala.
3. **Base:** kapak servosunu orta direğe, pitch servosunu sağ tutucuya M3 ile vidala. Kapak taşıyıcısını (kolu takılı) kapak servosunun miline tak, merkez vidayı taşıyıcıdaki Ø7 delikten sağ taraftan sık (bu adımda göz/çerçeve yok, erişim serbest). Kapak kapalıyken servo 112.5° olmalı (kinematics.json).
4. **Çerçeve:** iki yarıyı yaw_mount ile birleştir (4× M4×16), yaw servosunu yaw_mount'a M3 ile as, yaw krankını (kolu takılı) mile tak ve sık (krank −Z'ye, arkaya bakmalı).
5. Çerçeveyi base'e indir: sağ yan plakadaki kolu pitch servosunun miline geçir; merkez vidayı yan plakadaki Ø7 delikten **içeriden kısa (stubby) tornavidayla** sık (gözler henüz yok). Sonra **pivot_bracket**'ı sol yan plakanın dışına oturt, alttan 2× M4×16 havşa ile base'e vidala, M4×10'u dıştan yataktan geçirip yan plakaya vidala.
6. **Gözler:** yaw kolunu gözün altına M4×16 havşa ile (kolun ön ucundan) kilitle. Gözü çerçeve yarısının üst/alt kolları arasına koy, üst ve alt M4×16 havşa pimleri çerçeveye vidala (göz serbest dönmeli; sıkıysa gözdeki RUN deliğini 4.5 matkapla aç).
7. Lamayı göz kollarına ve kranka M4×10 ile bağla (kafa lamanın altında, vida kol/krankta sabit).
8. Kapakları taşıyıcının kulaklarına 2'şer M4×10 ile vidala (en son).
9. `out/kinematics.json → settings_suggestion` ile başla; yönleri donanımda doğrula (EYE_YAW modelde ters: `invert: true`).

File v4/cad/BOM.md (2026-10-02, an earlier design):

# Project Eye v4 (v3 revizyonu) — malzeme listesi

Sayılar `eye_v4.py` montaj kaydından (`check.py §8`). Ender 3 Neo, 0.4 nozül, PLA, 0.2 mm.
Toleranslar tolerans testiyle **henüz tam doğrulanmadı** (servo cebi ölçüsü kullanıcı testinden: boy +0.4, en +0.2).

## 1. Basılacak parçalar (`out/stl/`, baskı yönüne çevrilmiş, tabla z=0) — 16 farklı STL, 19 baskı

| STL | Adet | Boyut (mm) | Baskı yönü | Destek (check §7) |
|---|---|---|---|---|
| `eye` | 2 | 36×28×29 | alt düz yüz (y −13) tablada | Yok |
| `eye_lever` | 2 | 13×31×3.5 | düz | Yok |
| `coupler` (yaw laması, ortada geriye kıvrık) | 1 | 104×69×3.5 | düz | Yok |
| `yaw_crank` | **2** | 26×33×3.5 | düz | Yok. **Biri yaw, biri LIDS krankı** |
| `link_up` / `link_lo` (kapak lamaları) | 1+1 | 19×26×3.5 / 37×16×4.5 | düz | Yok |
| `frame_L`, `frame_R` (göz kafesleri) | 1+1 | 86×55×78 / 80×55×78 | **ön yüz tablada** | Yok (sarkma 120 / 320 mm²: frame_R'de LIDS servo kanadının alt kenarı ~28 mm köprü) |
| `yaw_mount` | 1 | 63×37×30 | plaka üst yüzü tablada, bacaklar yukarı | Yok |
| `lid_up_L`, `lid_up_R` (üst kapaklar + orta çubuk) | 1+1 | 40×21×90 / 41×21×68 | dış menteşe göbeği tablada (X dik) | **Destek önerilir** (kutup kubbesi + dudak altı, ~450 mm²). Havada ada yok. Brim önerilir |
| `lid_lo_L`, `lid_lo_R` (alt kapaklar + orta çubuk) | 1+1 | 26×26×88 / 26×20×76 | dış menteşe göbeği tablada | **Destek önerilir** (~300 mm²). Brim önerilir |
| `pivot_bracket` (sol pitch yatağı) | 1 | 11×40×62 | ayak tablada | Yok. Yatak deliği yatay (+0.2) |
| `base` | 1 | 212×89×74 | taban tablada | Yok |
| `mask` | 1 | 212×92×30 | **ön yüz tablada** | Yok |

Hepsi tek gövde, havada başlayan ada yok (`check.py §7`). En büyük parçalar (base, mask) 212 mm: 220 tablaya sığar.

## 2. Vidalar (eldeki malzeme)

| Vida | Adet | Nerede |
|---|---|---|
| **M4×10 yuvarlak** | **13** | göz kolu uçları 2 + yaw krank ucu 1 (lama pimleri, kafa lamanın altında); **kapak menteşeleri 4** (kafa üst kapak göbeğinin cebinde, alt kapaktan geçip kafes plakasına vidalı); sol pitch pimi 1; kapak lama pimleri 2 (U: üst kapakta sabit, L: alt kapakta sabit); orta bindirme 3 (üst 1, alt 2; radyal) |
| **M4×16 havşa** | **13** | göz üst pimi 2, alt pimi 2 (kafeste sabit, göz döner); yaw_mount ↔ kiriş 4 (kirişin altından); pivot_bracket ↔ base 2, maske ↔ base 2 (base'in altından); LIDS krank ucu pimi 1 (alt lamanın havşasında, krankta sabit) |
| **M3×10 yuvarlak** | **6 / 14** ✅ | göz kolu kilidi 2 (alttan, göze); SG90 kulağı 3 (her servoda **mil tarafı** kulak; kablo tarafı kulak kablo yarığına denk geliyor, vida yok — DECISIONS §2.3); orta üst bindirme 1 |
| SG90'ın küçük vidaları | 6 | servo kolu ↔ basılı parça (pitch: frame_R dış plakası; yaw ve LIDS: yaw_crank), göbeğe en yakın delikler (r≈7), ≤ 5 mm |

M2 / somun / pim / rotil / tel **kullanılmıyor**. Kulak delikleri 3.2 mm matkapla büyütülür.

## 3. Satın alınan / eldeki
- SG90 × 3 (kanal 0 EYE_YAW, 1 EYE_PITCH, 2 LIDS) + çift kollu kolları. Arduino Uno, 5 V ≥ 2 A.

## 4. Montaj sırası (önemli: kapaklar gözden ÖNCE, göz ARKADAN)
1. Kulak deliklerini 3.2 mm aç. Servoları 90°'ye getir (kol takmadan).
2. **Kollar:** pitch servosunun kolunu frame_R dış plakasına, yaw ve LIDS kollarını birer yaw_crank'e küçük vidalarla bağla (vida kafaları servo tarafında).
3. **Kapaklar (her göz için, kafes boşken):** alt kapak göbeğini kafes plakasının iç yüzüne, üst kapak göbeğini onun iç yüzüne hizala; M4×10'u **göz tarafından** üst göbeğin cebine koyup plakaya vidala (iki kutup). Kapaklar elle serbest dönene kadar geri al. Sol ve sağ kapak parçalarını ortada bindir: üst bindirmeye M4×10 + M3×10, alta 2× M4×10 (dışarıdan, radyal).
4. **Gözler:** kapaklar açıkken gözü **arkadan** kafese kaydır (üst düz yüz üst köprü göbeğinin altından geçer). Üst ve alt M4×16 havşa pimleri tak (göz serbest dönmeli; sıkıysa gözdeki RUN deliği 4.5). Göz kolunu alttan M3×10 ile göze kilitle (pimin arkasında).
5. **Kafesleri birleştir:** yaw_mount'u iki kafesin kirişine alttan 4× M4×16 ile bağla; yaw servosunu yaw_mount'a M3 ile as, yaw krankını (kollu) mile tak.
6. Yaw lamasını göz kollarına ve kranka M4×10 ile bağla (kafa lamanın altında).
7. **LIDS:** servoyu sağ kafesin kanadına cebinden geçir, mil tarafı kulağı M3 ile vidala; krankı (kollu) mile tak (kapaklar kapalıyken servo 102.3° — kinematics.json). Üst lamayı üst kapak pimine (M4×10), alt lamayı alt kapak pimine (M4×10) tak; iki lamayı krank ucuna M4×16 havşa ile (alt lamanın havşasından) bağla.
8. **Çerçeveyi base'e indir:** frame_R dış plakasındaki kolu pitch servosunun miline geçir (merkez vidası yok — DECISIONS §6.4). pivot_bracket'ı sol dış plakanın göbeğine oturt, alttan 2× M4×16 ile base'e, M4×10'u dıştan yataktan geçirip göbeğe vidala.
9. Maskeyi alttan 2× M4×16 ile base'e vidala.
10. `out/kinematics.json → settings_suggestion` ile başla. **LIDS aralığı v3'ten farklı: kapalı 102.3°, açık 77.7°.** `lid_follow_pitch` ayarını 0'a yakın başlat (kapaklar pitch'i mekanik izliyor).

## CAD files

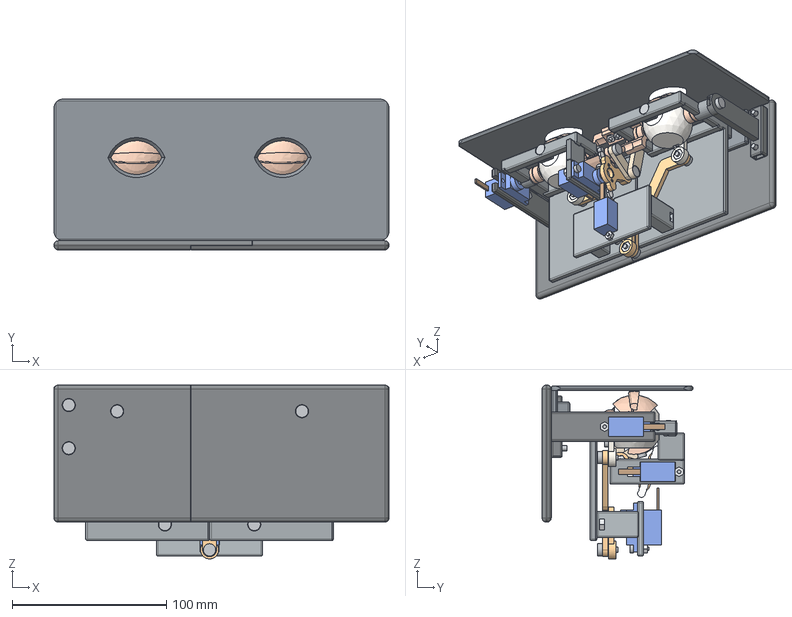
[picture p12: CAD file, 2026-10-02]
v5/cad/out/step/assembly.step
217.5 x 98.0 x 112.9 mm
eye_L
iris_L
pupil_L
eye_lever_L
scr_lock_L
nut_lock_L
scr_ltip_L
nut_ltip_L
eye_R
iris_R
pupil_R
eye_lever_R
scr_lock_R
nut_lock_R
scr_ltip_R
nut_ltip_R
frame_L
scr_ptop_L
scr_pbot_L
nut_ptop_L
nut_pbot_L
scr_lpin_Lo
nut_lpin_Lo
scr_lpin_Li
nut_lpin_Li
scr_ym_L63
frame_R
scr_ptop_R
scr_pbot_R
nut_ptop_R
nut_pbot_R
scr_lpin_Ro
nut_lpin_Ro
scr_lpin_Ri
nut_lpin_Ri
scr_ym_R63
scr_fpivot
nut_fpivot
servo_pitch
cable_pitch
horn_pitch
servo_yaw
cable_yaw
yaw_mount
scr_m3_yaw0
nut_m3_yaw0
nut_ym_L63
nut_ym_R63
horn_yaw
yaw_crank
scr_ctip
nut_ctip
coupler
servo_lid
cable_lid
scr_m3_lid0
nut_m3_lid0
lid_crank
horn_lid
link_up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

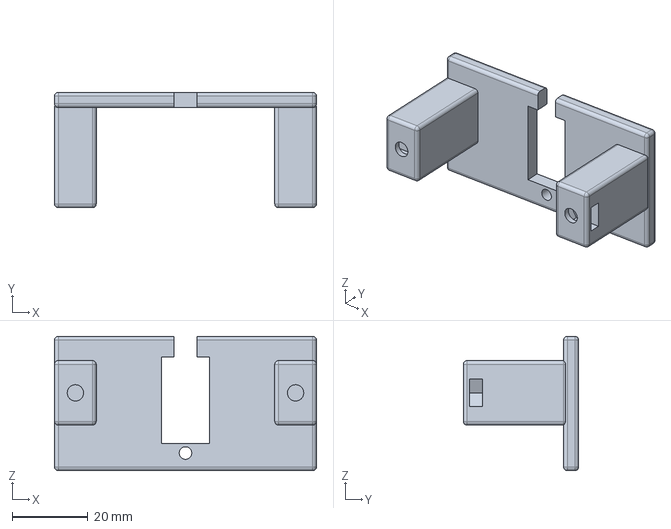
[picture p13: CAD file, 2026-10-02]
v5/cad/out/step/yaw_mount.step
69.0 x 30.4 x 35.4 mm

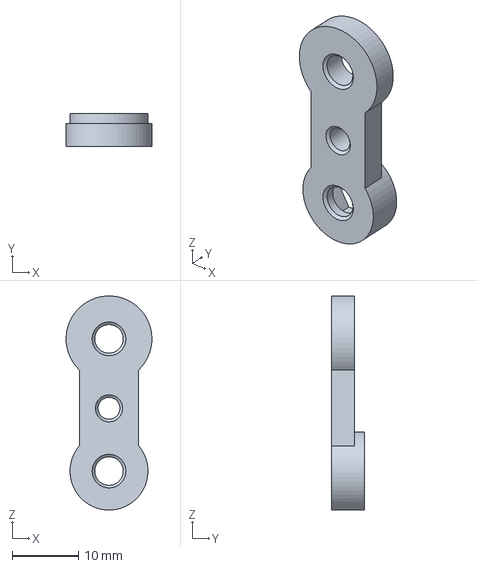
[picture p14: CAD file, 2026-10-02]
v5/cad/out/step/eye_lever.step
13.0 x 5.00 x 32.4 mm

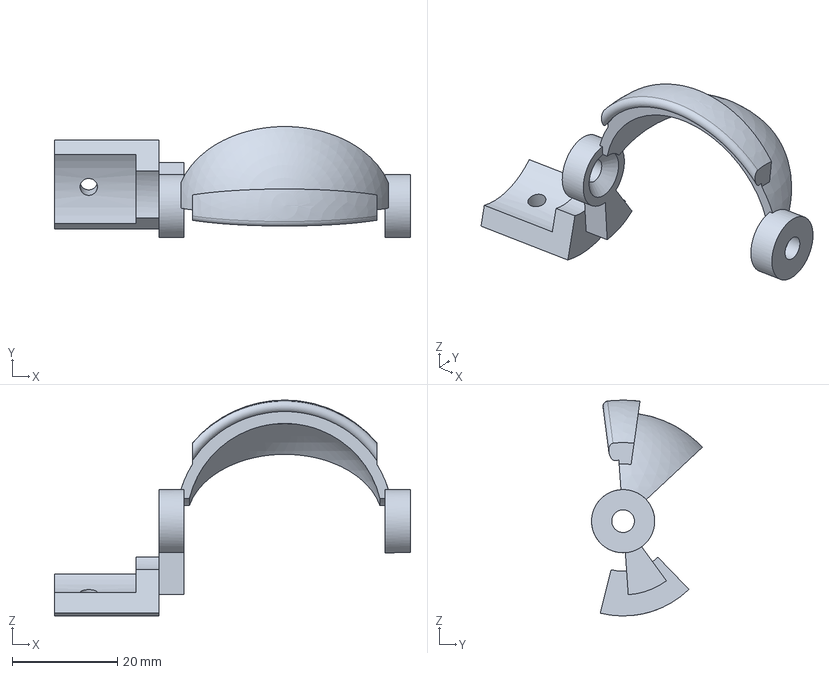
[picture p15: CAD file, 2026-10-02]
v5/cad/out/step/lid_up_R.step
67.6 x 21.1 x 41.0 mm

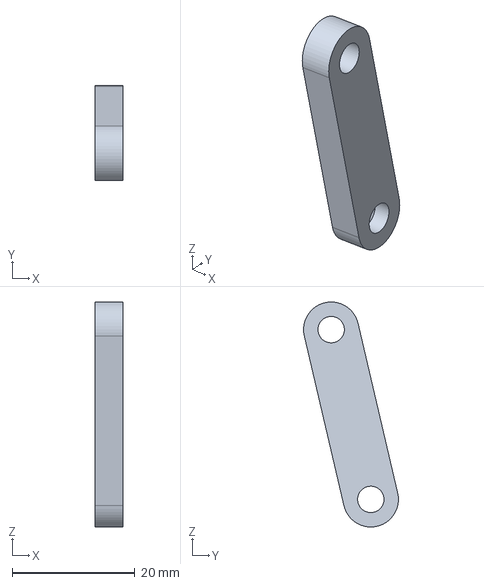
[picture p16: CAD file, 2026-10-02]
v5/cad/out/step/link_lo.step
4.50 x 15.5 x 36.7 mm

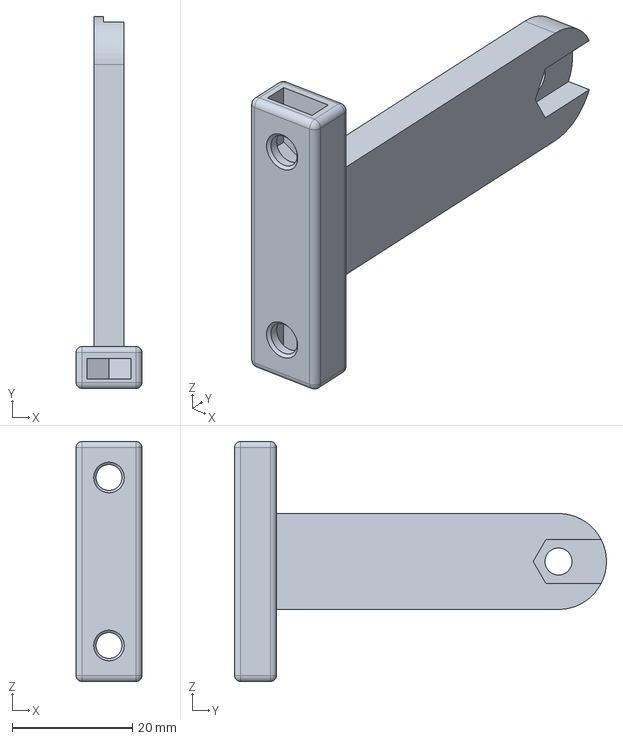
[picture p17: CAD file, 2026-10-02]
v5/cad/out/step/pivot_bracket.step
11.0 x 62.0 x 40.0 mm

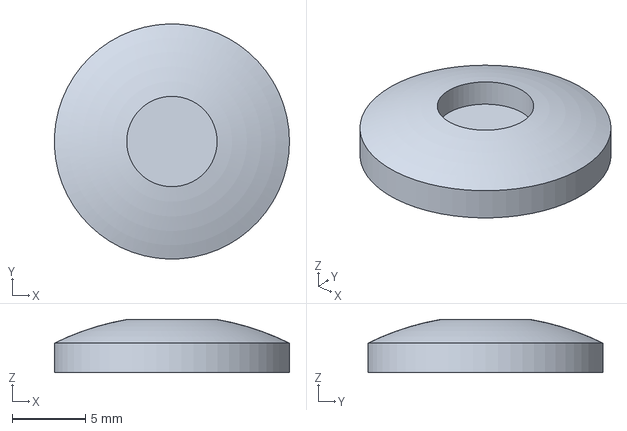
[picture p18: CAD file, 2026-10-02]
v5/cad/out/step/iris.step
16.0 x 16.0 x 3.61 mm

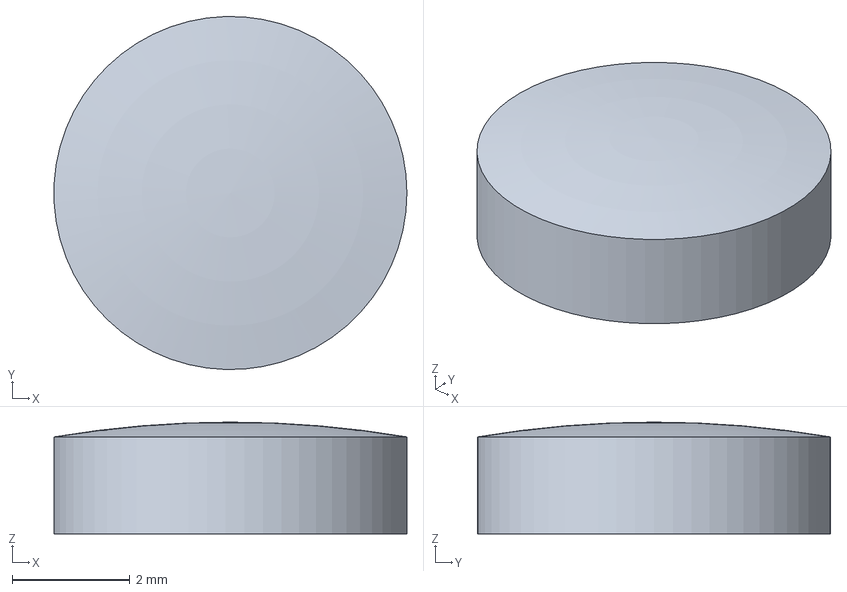
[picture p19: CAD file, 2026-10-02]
v5/cad/out/step/pupil.step
6.00 x 6.00 x 1.90 mm

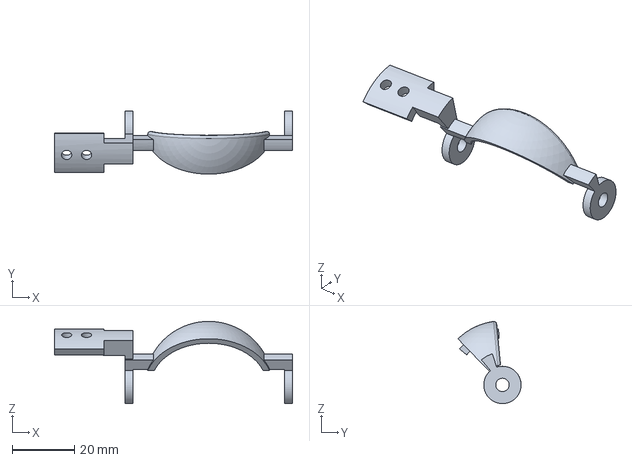
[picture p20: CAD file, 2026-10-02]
v5/cad/out/step/lid_lo_R.step
76.4 x 20.3 x 26.4 mm

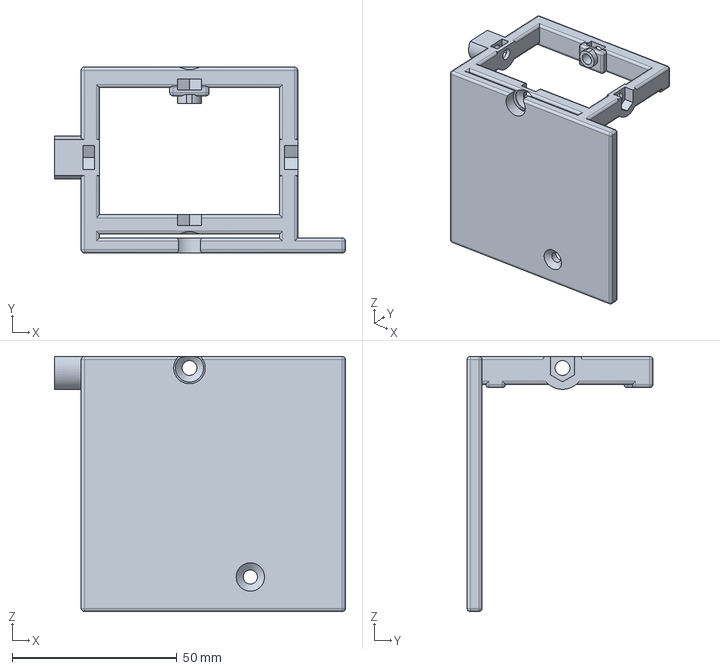
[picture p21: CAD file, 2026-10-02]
v5/cad/out/step/frame_L.step
88.4 x 56.5 x 77.5 mm

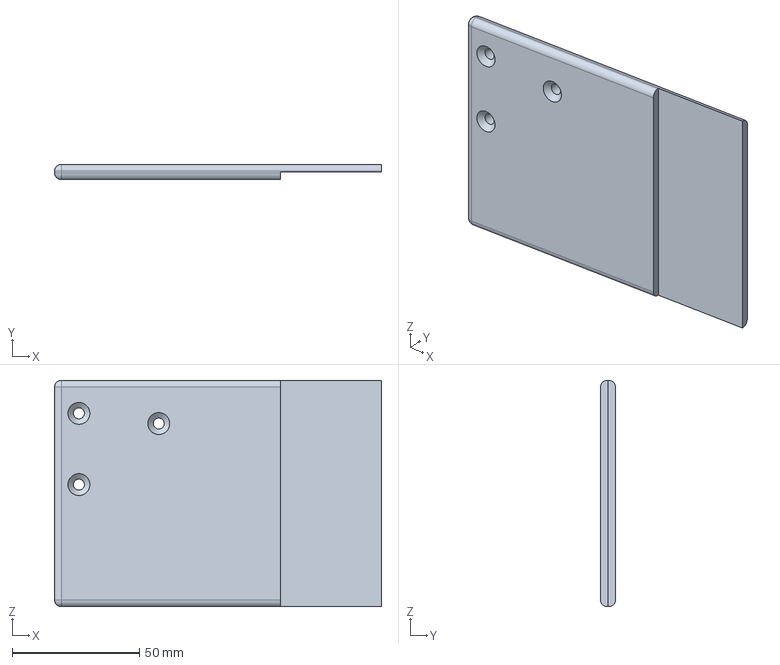
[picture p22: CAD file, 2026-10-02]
v5/cad/out/step/base_L.step
128.6 x 6.00 x 89.0 mm

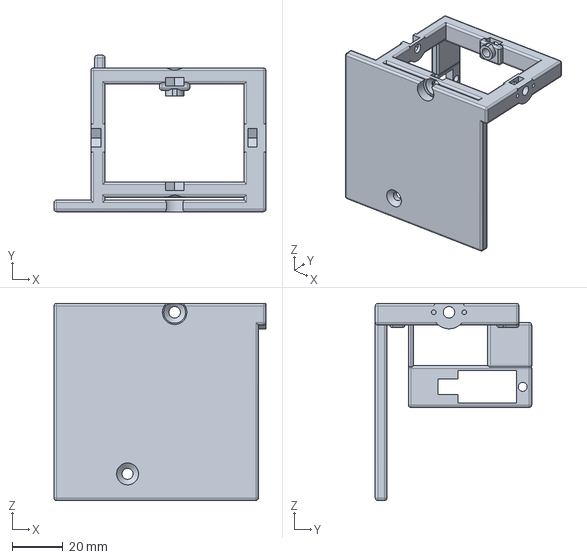
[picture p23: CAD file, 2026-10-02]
v5/cad/out/step/frame_R.step
83.3 x 61.5 x 77.5 mm

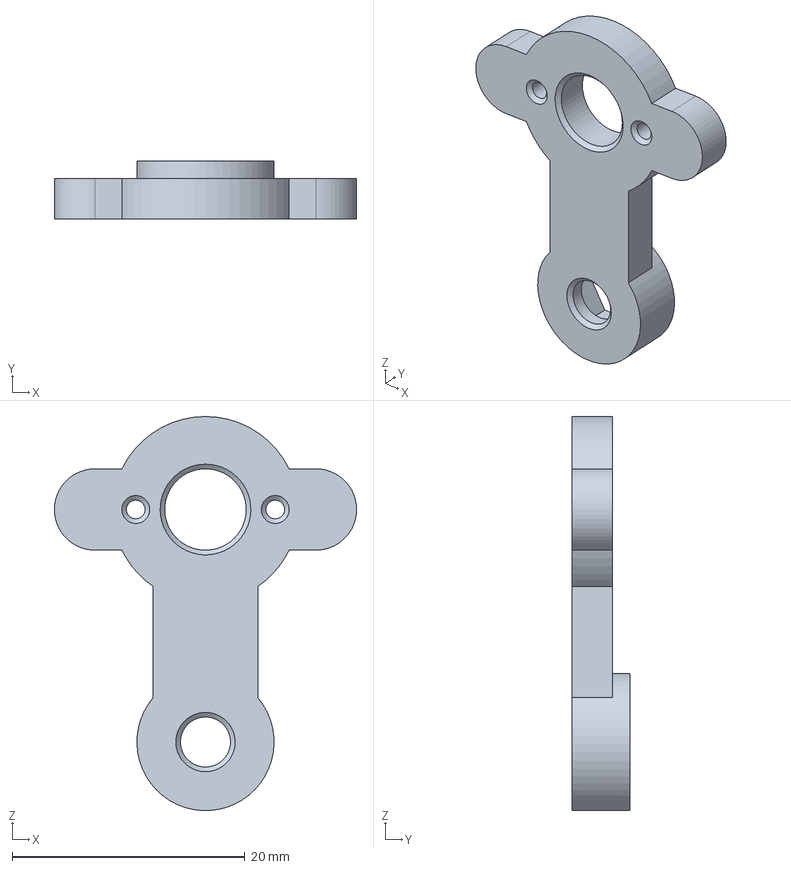
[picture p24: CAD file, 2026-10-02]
v5/cad/out/step/yaw_crank.step
26.0 x 5.00 x 33.9 mm

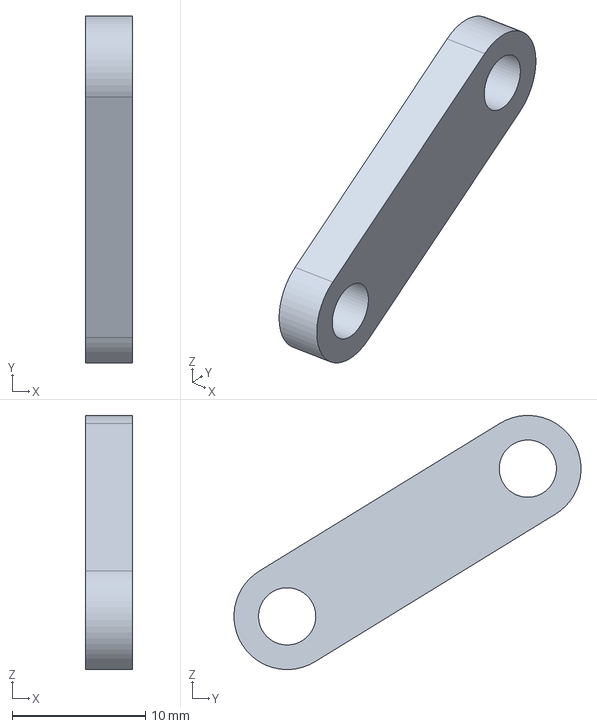
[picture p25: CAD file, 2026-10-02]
v5/cad/out/step/link_up.step
3.50 x 26.1 x 19.1 mm

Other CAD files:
v5/cad/out/step/lid_lo_L.step
v5/cad/out/step/coupler.step
v5/cad/out/step/base_R.step
v5/cad/out/step/lid_up_L.step
v2/cad/out/step/assembly.step
v2/cad/out/step/back_frame.step
v2/cad/out/step/base.step
v2/cad/out/step/eye_fork.step
v2/cad/out/step/eye_shell_L.step
v2/cad/out/step/eye_shell_R.step
v2/cad/out/step/fixed_fork.step
v2/cad/out/step/gobek.step
v2/cad/out/step/lid_link_lower.step
v2/cad/out/step/lid_link_upper.step
v2/cad/out/step/lid_lower_L.step
v2/cad/out/step/lid_lower_R.step
v2/cad/out/step/lid_upper_L.step
v2/cad/out/step/lid_upper_R.step
v2/cad/out/step/mask.step
v2/cad/out/step/mount_lid_servos_L.step
v2/cad/out/step/mount_lid_servos_R.step
v2/cad/out/step/mount_pitch_servo.step
v2/cad/out/step/pitch_link_L.step
v2/cad/out/step/pitch_link_R.step
v2/cad/out/step/rocker.step
v2/cad/out/step/rocker_bearing.step
v2/cad/out/step/yaw_coupler.step
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

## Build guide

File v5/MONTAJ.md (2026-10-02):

# Project Eye v5 — montaj sırası

Bu sıra `cad/check_montaj.py` ile **vida vida** denetlenir: her vidanın kafası kendi ekseni boyunca, o adıma kadar takılı
parçalara çarpmadan yerine sürülebiliyor ve arkasında ≥ 30 mm düz tornavida yolu var (menteşe vidaları hariç, bkz. 4).
Sonuç (2026-09-30): **35 vida, 0 imkânsız, 0 tornavida engeli**, 3 uyarı (M3 pan kafa servo gövdesine ~0.15 mm biniyor).
Göz alt montajının kafeslere arkadan kayması ayrıca 0–100 mm boyunca taranıp serbest bulundu (kapak açık ve kapalı).

**Takım:** yıldız tornavida (≥ 30 mm düz yol), **kısa uç** (≤ 20 mm, 1/4" uç parmakla ya da kısa uç tutucu — menteşe vidaları
için), küçük tornavida (servo kolu vidaları), pense/cımbız (somunlar). İsteğe bağlı: vida sabitleyici, PLA yapıştırıcısı.

**Genel kurallar**
- Somunlar parçalar ayrıyken cebine konur (oturmazsa havyayla ısıtıp bastır).
- Servo kulak vidası (M3 + somun) her serVoda **milden UZAK** kulaktan (mile yakın uçta kablo yarığı var).
- Servo kolu (çift kol) önce basılı parçaya küçük vidalarla vidalanır, **sonra** servo miline geçirilir.

## Adımlar

1. **Taban:** `base_L` ile `base_R`'yi ortadaki 40 mm bindirmeden yapıştır (sağ yarının alt dili, sol yarının üst dilinin altına).
2. **Pitch servosu → taban:** servoyu `base_R`'deki tutucuya tak; M3×10 + somun, milden uzak kulak.
3. **Pitch braketi → taban:** alttan 2× M4×16 havşa (somunlar braket ayağında).
4. **GÖZ ALT MONTAJI (kafeslerin dışında):**
   - iris + bebek gözlere bastır;
   - her göz kolunu M3×10 ile göze kilitle (alttan; somun gözün içinde);
   - kol ucu M4 somunlarını kolların uç ceplerine koy (cep üstten açık — göz üstüne gelince somun hapsolur);
   - bağlantı çubuğunu (`coupler`) iki kolun ucuna **alttan** M4×10 ile vidala (eklem serbest kalana kadar sık).
   Artık iki göz + iki kol + bağlantı çubuğu tek parça.
5. **Kafes L — kapaklar (göz YOKKEN):** alt + üst kapak göbeklerini plakaya hizala; 2× M4×16 havşa **göz tarafından**
   (kafesin içinden) üst göbeğin havşasından geçir, plakadaki somuna vidala. Karşı kutup yaklaşık 40 mm ötede:
   **kısa uç** kullan. Kapaklar serbest dönene kadar geri al (+ vida sabitleyici).
6. **Kapak lamaları (sol kafeste, göz ve sağ kafes YOKKEN):**
   - üst lamayı U pimine: M4×10, **sol taraftan** (kafes içinden), üst kapak kolundaki kanaldan geçerek; vida kapak tırnağına kendi dişini açar;
   - alt lamayı L pimine: M4×10 (+ alt kapak tırnağındaki somun).
   Lamaların krank uçları **boşta** kalır (sonra A pimi).
7. **Kafes R:** pitch servo kolunu dış plakaya küçük vidalarla vidala (**servo yokken**).
8. **Kafes R — kapaklar (göz yokken):** 5. adım gibi.
9. **Kafesleri yan yana koy — kapak bindirme vidaları (gözlerden ÖNCE, kapaklar KAPALI):** üst bindirme 1× M3×10,
   alt bindirme 2× M3×10, dışarıdan; somunlar sol kapakların iç katında. İsteğe bağlı: üst bindirme yüzeyine yapıştırıcı.
10. **Gözler:** 4. adımdaki alt montajı **iki kafese birlikte arkadan** kaydır. Üst göz pimleri üstten (M4×16, somun
    köprüde), alt pimler alttan kirişteki erişim deliğinden (M4×16, somun alt köprünün üst yüzünde).
11. **Kapak servosu → kanat (gözlerden SONRA):** lamaları yukarı çevirip yolu aç; servoyu gövde altı önde, kanadın cebine
    geçir (kulaklar kanadın iç yüzüne oturur); M3×10 + somun, milden uzak kulak.
12. **Kapak krankı alt montajı:** servo kolunu krank'a vidala (servo yokken); A pimi somununu krank göbeğine koy.
13. **Kapak krankı → servo** (kapalıyken 102.3°); iki lamanın ucunu krank ucuna M4×16 havşa ile bağla (A pimi).
14. **Yaw servosu → yaw_mount:** M3×10 + somun, milden uzak kulak.
15. **Yaw krankı alt montajı:** servo kolunu kranka vidala (servo yokken); krank ucu somununu cebe koy.
16. **yaw_mount → kafes altı:** kirişin altından 2× M4×16 havşa (somunlar bacaklarda).
17. **Yaw krankı → servo** (90°), krank ucunu bağlantı çubuğuna M4×10 ile vidala.
18. **Çerçeve → taban:** `frame_R`'nin pitch kolunu pitch servo miline geçir; sol pimi (M4×10) dıştan brakete, somun yatakta.
19. **Maske (en son):** alttan 2× M4×16 havşa.

## Denetim
```
cd v5/cad
PYTHONUTF8=1 ../../../../.venv-cad/Scripts/python.exe check_montaj.py            # sıralı (bu belge)
PYTHONUTF8=1 ../../../../.venv-cad/Scripts/python.exe check_montaj.py --detay    # adım adım her vida
PYTHONUTF8=1 ../../../../.venv-cad/Scripts/python.exe check_montaj.py --takili   # her şey takılıyken (bilgi)
```
Denetlenmeyenler: somunların cebe konma yolu, kabloların yönlendirilmesi, 11. adımda lamaların yukarı çevrildiği poz
(lamalar hariç tutularak tarandı; krank uçları boşta olduğu için pimleri etrafında döner), elle tutma/görme zorluğu.

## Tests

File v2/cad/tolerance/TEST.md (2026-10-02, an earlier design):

# Tolerans testi — Ender 3 Neo

Asıl parçaları basmadan önce yazıcının gerçek geçmelerini ölçmek için.
Her test, `params.py`'deki bir tolerans değerini onun etrafında birkaç varyantla dener.
Sen hangisinin oturduğunu söylersin, o değer `params.py`'ye yazılır ve bütün parçalar yeniden üretilir.

## Basılacaklar (`out/`)
| Dosya | Ne test eder | Yaklaşık boyut |
|---|---|---|
| `tolerans_plaka.stl` | M2 vida delikleri, Ø2 pim delikleri, M2 vida başı havşası (5 satır × 5 varyant) | 67 × 51 × 5.6 |
| `tolerans_gobek.stl` + `tolerans_catal.stl` | Kardan göbeği (8 mm küp) ile çatal arasındaki boşluk (4 varyant) | küp 8 mm, tarak 61 × 18 × 12 |
| `tolerans_servo.stl` | SG90 gövde cebi (3 varyant) | 85 × 23 × 6.6 |

Hepsi tek tablaya sığar. Düz yüzleri tablaya bakacak şekilde yönlendirilmiş, destek gerekmez.

## Dilimleyici ayarları (PLA)
- Katman 0.2 mm, duvar (wall) 3, üst/alt 4 katman, doluluk %20, destek yok.
- **Önemli:** "Horizontal Expansion" ve "Hole Horizontal Expansion" (Cura) ya da "XY size compensation" (PrusaSlicer) **0** olsun. Test, yazıcının ham davranışını ölçmeli.
- Asıl parçalarda da **aynı ayarları ve aynı filamenti** kullan; aksi halde test geçersiz olur.

## Gerekenler
- 1–2 adet **M2 silindir başlı vida** (ISO 4762, 6–10 mm). Somun gerekmiyor: tasarımda somun yok.
- **Ø2 çelik pim** (DIN 7 / ISO 2338; yoksa Ø2 matkap ucunun sapı da iş görür)
- 1 adet **SG90**

## Nasıl denenir
Plakada satırlar harfle (A–E, sol kenar), varyantlar numarayla (1–5, üst kenar) işaretli.
Ortadaki varyant (3), `params.py`'deki şu anki değerdir.

| Test | Değerler 1→5 (mm) | Doğru olan |
|---|---|---|
| **A** M2 kılavuzsuz vida deliği | 1.5 1.6 1.7 1.8 1.9 | Vida elle, zorlanarak kendi yolunu açar ve **sıkıca tutar**; plastik çatlamaz |
| **B** M2 geçiş deliği | 2.0 2.1 2.2 2.3 2.4 | Vida **serbestçe geçer**, yanlara neredeyse hiç sallanmaz |
| **C** Ø2 pim, sıkı geçme | 1.85 1.90 1.95 2.00 2.05 | Pim hafif bastırarak ya da hafif çekiçle girer ve **elle çıkmaz** |
| **D** Ø2 pim, dönen geçme | 2.15 2.20 2.25 2.30 2.35 | Plaka pim üzerinde **serbest döner**, boşluk hissedilmez |
| **E** M2 vida başı havşası | 3.9 4.0 4.2 4.4 4.6 | Vida kafası (Ø3.8) **sürtmeden** havşaya iner ve yüzeyle aynı hizada kalır |
| **F** Göbek–çatal (tarak, 1→4) | yuva 8.6 8.8 9.0 9.2 | Küp yuvada **rahat döner**, yana oynaması az |
| **S** SG90 cebi (1→3) | boşluk 0.2 0.3 0.4 | Servo elle **itilince girer**, sallanmaz |

## Raporlama
Her test için doğru oturan varyantı yaz, örneğin:

```
A3 B4 C2 D3 E3 F2 S2
```

İki varyant arasında kaldıysa ikisini de yaz (`A3-4`). Hiçbiri olmadıysa yönünü söyle (`C: 1 bile gevşek`).

## Bilinen sınırlama
Bu testteki delikler **dikey** basılıyor (delik ekseni Z). Yatay basılan deliklerde (ekseni tablaya paralel)
FDM delikleri genelde biraz daha küçük ve oval çıkar. Asıl parçalarda yatay basılması gereken delikler varsa,
onlar için ayrıca küçük bir test gerekebilir. Parçalar netleşince buna bakacağız.

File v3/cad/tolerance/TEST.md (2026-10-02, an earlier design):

# Tolerans testi — Project Eye v3 (POC, M3/M4) · Ender 3 Neo · OrcaSlicer

POC eldeki vidalarla yapılıyor: **M4×10 yuvarlak kafa, M4×16 havşa (koni) kafa, M3×10 yuvarlak kafa.**
Bu test, bu vidaların senin yazıcında hangi delik ölçülerine oturduğunu bulur. Test bağımsız bir kontrolden geçti ve düzeltildi.

## Basılacaklar
| Dosya | Ne test eder | Öncelik |
|---|---|---|
| `tolerans_plaka.stl` | A–E: M3/M4 delikleri, M4 vida-pim eklemi, M4 havşa (75 × 63 × 6.6 mm) | **Asıl test** |
| `tolerans_servo_tek.stl` | S: tek SG90 cebi, 22.9 × 12.9 (ölçtüğün servo 22.5 × 12.5 + 0.4 pay), kablo yarıklı | Önemli |
| `tolerans_gobek.stl` + `tolerans_catal.stl` | F: iki düz yüz arasındaki kayma boşluğu | İsteğe bağlı (aşağıya bak) |

## Dilimleyici (OrcaSlicer, "Epic POC" profili)
- Profil zaten doğru: 0.2 mm, 3 duvar, %20, destek yok, **X-Y hole compensation 0, X-Y contour compensation 0, Elephant foot compensation 0, polyholes kapalı.**
- Asıl parçalar da **aynı profil ve aynı filamentle** basılacak.

## Denemeden önce
1. **Deliklerin alt ağzı:** Plakadaki deliklerin altında küçük bir pah var. Yine de alt ağızda çapak varsa bir çakıyla temizle.
2. **Vidalar hep yazılı (üst) yüzden girsin.**
3. **Kumpasın varsa ölç:** M4 koni kafanın **kafa çapı** ve SG90 gövdesinin **en ve boyu** (datasheet: 22.8 × 12.4).

## Nasıl karar verilir
Plakada satırlar harfle (A–E, sol kenar), varyantlar numarayla (1–5, üst kenar) işaretli.

| Test | 1 → 5 (mm) | Doğru olan |
|---|---|---|
| **A** M3 vidalanan delik | 2.5 2.6 2.7 2.8 2.9 | Vidayı sonuna kadar sık. Sıkınca **boşa dönmeyen EN BÜYÜK** delik. Söküp tekrar tak, ikinci takışta da tutmalı. |
| **B** M3 geçiş deliği | 3.2 3.3 3.4 3.5 3.6 | Vida elle, **dişi takılmadan geçen EN KÜÇÜK** delik |
| **C** M4 vidalanan delik | 3.3 3.4 3.5 3.6 3.7 | A ile aynı kural, M4 vidayla: **boşa dönmeyen EN BÜYÜK**, ikinci takışta da tutan |
| **D** M4 vida-pim eklemi ⭐ | 4.2 4.3 4.4 4.5 4.6 | M4 vidayı geçir. **Vida parmakla sürtünmeden dönen EN KÜÇÜK** delik. |
| **E** M4 havşa | 8.0 8.3 8.6 8.9 9.2 | M4×16 koni kafa **yüzeyle aynı hizaya ya da biraz altına inen EN KÜÇÜK** havşa |
| **S** SG90 cebi (tek) | cep 22.9 × 12.9 | Rapor: **"S sıkı"** (girmiyor/zorla giriyor), **"S tam"** (elle itilince giriyor, sallanmıyor) ya da **"S bol"** (sallanıyor) |
| **F** (isteğe bağlı, tarak 1→4) | yuva 8.6 8.8 9.0 9.2 | Küp yuvaya **sürtünmeden kayan EN DAR** yuva |

**F hakkında:** Bu test sadece iki düz yüz arasındaki kayma boşluğunu ölçüyor. POC'deki vida-pim eklemlerinde bu boşluğu daha çok vidanın ne kadar sıkıldığı belirler. Zamanın darsa F'yi atlayabilirsin, varsayılan 0.4 mm ile devam ederiz.

## Rapor
Tek satır, her test için doğru olan numara:
```
A3 B2 C3 D4 E3 S2 F2
```
- Arada kaldıysan: `A3-4`
- Hiçbiri olmadıysa yönünü yaz: `D: 5 bile sıkı`, `E: 1 bile gömülüyor`
- Ölçtüysen ekle: `M4 kafa 8.4`, `SG90 22.9 × 12.5`

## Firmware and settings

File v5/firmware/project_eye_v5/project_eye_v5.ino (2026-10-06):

/*
 * Project Eye v5 - firmware (Arduino Uno)
 * ==========================================================================
 * Iki goz (bagli) + dort kapak (tek servo), 3 x SG90. v3 firmware'inin
 * kopyasi: ayni protokol, banner 'EYE v5 READY', v4 mekanik limitleri.
 *
 * Kanal haritasi:
 *   kanal 0  EYE_YAW    D3
 *   kanal 1  EYE_PITCH  D5
 *   kanal 2  LIDS       D6   (dort kapak: 2 ust + 2 alt, tek servo + dort-cubuk)
 *
 * GUC: servolar HARICI 5 V (>= 2 A yeterli, 3 A onerilir) kaynaktan beslenir,
 * GND Uno ile ORTAK. Uno'nun 5 V pininden servo beslemeyin.
 *
 * Seri protokol (115200 baud, satir sonu '\n', ASCII; '\r' yok sayilir):
 *   PC -> Arduino
 *     S a0 a1 a2            3 kanalin ham servo acisi (0-180, ondalik olur)
 *     D                     tum servolari birak (detach)
 *     A 1 | A 0             kendi basina "canli" (idle) modu ac / kapat
 *     ?                     durum sorgusu
 *   Arduino -> PC
 *     EYE v5 READY          acilista bir kez
 *     OK                    gecerli S / D / A komutu
 *     ERR <mesaj>           gecersiz komut (satir islenmez)
 *     STATE a0 a1 a2 idle=<0|1>   '?' cevabi (anlik konum; idle = su an canli modda mi)
 *
 * Guvenlik:
 *   - Her aci kanal basina SABIT mekanik limite kirpilir (LIMIT_MIN/MAX =
 *     cad/out/kinematics.json "limits_checked", PAY YOK: disi DOGRULANMADI).
 *   - Her kanal hedefe en fazla 600 deg/s ile gider (millis tabanli, bloklamaz).
 *   - Bozuk / asiri uzun satir, eksik/fazla arguman, 0-180 disi -> ERR, hareket yok.
 *
 * Idle: 2 sn S gelmezse (idle acik ve servolar bagli ise) rastgele sakkadlar,
 * 3-6 sn'de bir kirpma, yavas kapak nefesi; kapak bakisin pitch'ini takip eder.
 * Ilk S'de PC kontrolu geri alir. '?' ve 'A' idle sayacini sifirlamaz.
 * Idle, PC'siz calistigi icin kalibrasyonu asagidaki derleme-zamani IDLE_*
 * sabitlerinden alir (settings.json ile ayni tutun).
 *
 * control/sim.py bu dosyanin Python esdegeridir; tests/test_firmware_sync.py
 * sabitlerin ayni kaldigini kontrol eder.
 */

#include <Servo.h>
#include <stdlib.h>
#include <string.h>
#include <math.h>

#define FW_BANNER "EYE v5 READY"

const uint8_t NUM_CH = 3;
const uint8_t PINS[NUM_CH] = {3, 5, 6};

//                                YAW     PITCH   LIDS
// KALIBRASYON (kullanici, 2026-09-30 18:50, control/kalibrasyon.json): yaw ve kapak sinirlari elde bulundu;
// pitch modelden (70..110). Mekanik model: yaw 65..115, kapak 77.71..102.29 (krank dis kaymasi yuzunden farkli).
const float LIMIT_MIN[NUM_CH] = { 45.0f,  70.0f,  80.0f};
const float LIMIT_MAX[NUM_CH] = {111.0f, 110.0f, 115.0f};

const float MAX_SPEED_DEG_S = 600.0f;
const uint16_t SERVO_US_MIN = 544;
const uint16_t SERVO_US_MAX = 2400;
const unsigned long TICK_MS = 5;
const unsigned long IDLE_TIMEOUT_MS = 2000;
const uint8_t LINE_MAX = 64;

// Idle kalibrasyonu (settings.json = kinematics.json onerisi)
const float IDLE_EYE_CENTER[2] = {78.0f, 90.0f};        // kalibrasyon: yaw merkez 78
const float IDLE_EYE_DEG_PER_UNIT[2] = {33.0f, 20.0f};  // yaw yonu idle'da onemsiz (simetrik)
const float IDLE_LID_CLOSED = 115.0f;                  // kalibrasyon: tam kapali
const float IDLE_LID_OPEN = 80.0f;                     // kalibrasyon: tam acik
const float IDLE_LID_FOLLOW_PITCH = 0.0f;  // v4: kapaklar pitch cercevesinde, pitch'i MEKANIK izler
const float IDLE_GAZE_U_MAX = 0.6f;
const float IDLE_GAZE_V_MAX = 0.0f;   // 2026-10-06: pitch servosu "olu" (SG90 yetmiyor) -> idle'da pitch sabit
const float IDLE_BREATH_BASE = 0.72f;
const float IDLE_BREATH_AMP = 0.12f;
const float IDLE_BREATH_PERIOD_S = 5.0f;
const unsigned long IDLE_SACCADE_MIN_MS = 400;
const unsigned long IDLE_SACCADE_MAX_MS = 2500;
const unsigned long IDLE_BLINK_MIN_MS = 3000;
const unsigned long IDLE_BLINK_MAX_MS = 6000;
const unsigned long IDLE_BLINK_CLOSED_MS = 120;
const float BOOT_LID_OPENNESS = 0.8f;

// Buton (kullanici 2026-09-30): D2 <-> GND, dahili pull-up. Basinca dogal hareket (idle) baslar, tekrar basinca
// notr poza (acilis pozu: gozler duz, kapaklar %80 acik) doner. Acilista notr (idle kapali). Karttaki LED (D13) = idle acik.
// Seri komut A 1 / A 0 ayni anahtari degistirir.
// 2026-10-06: PC kontrolu suruyorsa (son S < IDLE_TIMEOUT_MS ve idle degil) buton idle'i DEGISTIRMEZ, yalniz
// "BTN" satiri yazar -> tracker sonraki moda gecer. Eski PC yazilimi bilinmeyen satiri yok sayar.
const uint8_t BUTTON_PIN = 2;
const unsigned long BUTTON_DEBOUNCE_MS = 40;
const bool IDLE_AT_BOOT = false;

// --------------------------------------------------------------------------
Servo servos[NUM_CH];
float pos[NUM_CH];
float target[NUM_CH];
uint16_t lastUs[NUM_CH];

bool attached = false;
bool idleEnabled = IDLE_AT_BOOT;
bool idleActive = false;
unsigned long lastSMs = 0;
unsigned long lastTickMs = 0;

float idleU = 0.0f, idleV = 0.0f;
unsigned long idleNextSaccadeMs = 0;
unsigned long idleNextBlinkMs = 0;
unsigned long idleBlinkStartMs = 0;
bool idleBlinking = false;

char lineBuf[LINE_MAX + 1];
uint8_t lineLen = 0;
bool lineOverflow = false;
bool lineBadChar = false;

// --------------------------------------------------------------------------
static float clampf(float v, float lo, float hi) {
  if (v < lo) return lo;
  if (v > hi) return hi;
  return v;
}

// Kalibrasyon modu (C 1 / C 0, kullanici 2026-09-30): sinirlar her yone CAL_MARGIN acilir (0..180 icinde).
// Yalniz kalibrasyon panelinden kullanilir; kapanista normal mekanik sinirlara donulur.
const float CAL_MARGIN = 20.0f;
bool calMode = false;
static float clampToLimit(uint8_t ch, float deg) {
  if (calMode) return clampf(deg, max(0.0f, LIMIT_MIN[ch] - CAL_MARGIN), min(180.0f, LIMIT_MAX[ch] + CAL_MARGIN));
  return clampf(deg, LIMIT_MIN[ch], LIMIT_MAX[ch]);
}

static uint16_t degToUs(float deg) {
  float us = SERVO_US_MIN + (deg / 180.0f) * (float)(SERVO_US_MAX - SERVO_US_MIN);
  return (uint16_t)(us + 0.5f);
}

static void writeServo(uint8_t ch, bool force) {
  uint16_t us = degToUs(pos[ch]);
  if (force || us != lastUs[ch]) {
    servos[ch].writeMicroseconds(us);
    lastUs[ch] = us;
  }
}

static void attachAll() {
  if (attached) return;
  for (uint8_t i = 0; i < NUM_CH; i++) {
    writeServo(i, true);  // attach'tan once darbe: servo 90'a ziplamasin
    servos[i].attach(PINS[i], SERVO_US_MIN, SERVO_US_MAX);
  }
  attached = true;
}

static void detachAll() {
  for (uint8_t i = 0; i < NUM_CH; i++) servos[i].detach();
  attached = false;
}

static float lidAngle(float openness) {
  openness = clampf(openness, 0.0f, 1.0f);
  return IDLE_LID_CLOSED + openness * (IDLE_LID_OPEN - IDLE_LID_CLOSED);
}

static void sendErr(const char *msg) {
  Serial.print(F("ERR "));
  Serial.println(msg);
}

static void stepMotion(float dt) {
  float maxStep = MAX_SPEED_DEG_S * dt;
  for (uint8_t i = 0; i < NUM_CH; i++) {
    float d = target[i] - pos[i];
    if (d > maxStep) d = maxStep;
    else if (d < -maxStep) d = -maxStep;
    pos[i] += d;
    if (attached) writeServo(i, false);
  }
}

// --------------------------------------------------------------------------
// Idle
// --------------------------------------------------------------------------
static void idleEnter(unsigned long now) {
  idleActive = true;
  idleNextSaccadeMs = now;
  idleNextBlinkMs = now + (unsigned long)random(IDLE_BLINK_MIN_MS, IDLE_BLINK_MAX_MS + 1);
  idleBlinking = false;
}

static void idleUpdate(unsigned long now) {
  if ((long)(now - idleNextSaccadeMs) >= 0) {
    if (random(100) < 30) {
      idleU = random(-15, 16) / 100.0f;
      idleV = random(-10, 11) / 100.0f;
    } else {
      idleU = random(-(long)(IDLE_GAZE_U_MAX * 100), (long)(IDLE_GAZE_U_MAX * 100) + 1) / 100.0f;
      idleV = random(-(long)(IDLE_GAZE_V_MAX * 100), (long)(IDLE_GAZE_V_MAX * 100) + 1) / 100.0f;
    }
    idleNextSaccadeMs = now + (unsigned long)random(IDLE_SACCADE_MIN_MS, IDLE_SACCADE_MAX_MS + 1);
  }

  if (!idleBlinking && (long)(now - idleNextBlinkMs) >= 0) {
    idleBlinking = true;
    idleBlinkStartMs = now;
  }
  if (idleBlinking && now - idleBlinkStartMs >= IDLE_BLINK_CLOSED_MS) {
    idleBlinking = false;
    idleNextBlinkMs = now + (unsigned long)random(IDLE_BLINK_MIN_MS, IDLE_BLINK_MAX_MS + 1);
  }

  float phase = (float)(now % (unsigned long)(IDLE_BREATH_PERIOD_S * 1000.0f)) /
                (IDLE_BREATH_PERIOD_S * 1000.0f);
  float openness = IDLE_BREATH_BASE + IDLE_BREATH_AMP * sinf(phase * 2.0f * (float)M_PI);
  if (idleBlinking) openness = 0.0f;

  // kapak pitch takibi: v4'te kapaklar pitch'i MEKANIK izler, katsayi 0 (eye_control.py ile ayni formul)
  float upper = openness + IDLE_LID_FOLLOW_PITCH * 0.5f * idleV * openness;

  target[0] = clampToLimit(0, IDLE_EYE_CENTER[0] + idleU * IDLE_EYE_DEG_PER_UNIT[0]);
  target[1] = clampToLimit(1, IDLE_EYE_CENTER[1] + idleV * IDLE_EYE_DEG_PER_UNIT[1]);
  target[2] = clampToLimit(2, lidAngle(upper));
}

static void idleStop() {
  idleActive = false;
  idleBlinking = false;
  for (uint8_t i = 0; i < NUM_CH; i++) target[i] = pos[i];
}

// notr poz: acilis pozu (gozler merkez, kapaklar BOOT_LID_OPENNESS)
static void goNeutral() {
  idleStop();
  target[0] = clampToLimit(0, IDLE_EYE_CENTER[0]);
  target[1] = clampToLimit(1, IDLE_EYE_CENTER[1]);
  target[2] = clampToLimit(2, lidAngle(BOOT_LID_OPENNESS));
  attachAll();
}

static void pollButton(unsigned long now) {
  static bool ham = HIGH, kararli = HIGH, hazir = false;   // hazir: bir kez BIRAKILMIS (HIGH) goruldu mu
  static unsigned long degisim = 0;
  bool r = digitalRead(BUTTON_PIN);
  if (r != ham) { ham = r; degisim = now; }
  if (now - degisim >= BUTTON_DEBOUNCE_MS && r == HIGH) hazir = true;   // yanlis bagli (surekli LOW) buton acilista tetiklemez
  if (now - degisim >= BUTTON_DEBOUNCE_MS && r != kararli) {
    kararli = r;
    if (kararli == LOW && hazir) {              // basildi (birakma yok sayilir)
      if (!idleActive && now - lastSMs < IDLE_TIMEOUT_MS) { Serial.println(F("BTN")); return; }   // PC surerken: PC'ye bildir
      if (idleEnabled) { idleEnabled = false; goNeutral(); }
      else { idleEnabled = true; attachAll(); idleEnter(now); }
    }
  }
}

// --------------------------------------------------------------------------
// Komutlar
// --------------------------------------------------------------------------
static bool parseNumber(const char *tok, float &out) {
  if (tok == NULL || *tok == '\0') return false;
  char *end = NULL;
  double v = strtod(tok, &end);
  if (end == tok || *end != '\0') return false;
  if (isnan(v) || isinf(v)) return false;
  out = (float)v;
  return true;
}

static void cmdState() {
  Serial.print(F("STATE"));
  for (uint8_t i = 0; i < NUM_CH; i++) {
    Serial.print(' ');
    Serial.print(pos[i], 1);
  }
  Serial.print(F(" idle="));
  Serial.println(idleActive ? 1 : 0);
}

static void handleLine(char *line, unsigned long now) {
  const char *delim = " \t";
  char *cmd = strtok(line, delim);
  if (cmd == NULL) return;
  if (cmd[1] != '\0') { sendErr("unknown command"); return; }

  char c = cmd[0];
  if (c >= 'a' && c <= 'z') c -= 32;

  if (c == 'S') {
    float v[NUM_CH];
    for (uint8_t i = 0; i < NUM_CH; i++) {
      char *tok = strtok(NULL, delim);
      if (tok == NULL) { sendErr("S needs 3 angles"); return; }
      if (!parseNumber(tok, v[i])) { sendErr("bad number"); return; }
      if (v[i] < 0.0f || v[i] > 180.0f) { sendErr("angle out of 0-180"); return; }
    }
    if (strtok(NULL, delim) != NULL) { sendErr("S needs 3 angles"); return; }
    for (uint8_t i = 0; i < NUM_CH; i++) target[i] = clampToLimit(i, v[i]);
    idleActive = false;
    idleBlinking = false;
    lastSMs = now;
    attachAll();
    Serial.println(F("OK"));
  } else if (c == 'D') {
    if (strtok(NULL, delim) != NULL) { sendErr("D takes no args"); return; }
    idleActive = false;
    detachAll();
    for (uint8_t i = 0; i < NUM_CH; i++) target[i] = pos[i];
    Serial.println(F("OK"));
  } else if (c == 'A') {
    char *tok = strtok(NULL, delim);
    if (tok == NULL || strtok(NULL, delim) != NULL || tok[1] != '\0' ||
        (tok[0] != '0' && tok[0] != '1')) {
      sendErr("A needs 1 or 0");
      return;
    }
    idleEnabled = (tok[0] == '1');
    if (!idleEnabled && idleActive) idleStop();
    Serial.println(F("OK"));
  } else if (c == 'C') {
    char *tok = strtok(NULL, delim);
    if (tok == NULL || strtok(NULL, delim) != NULL || tok[1] != '\0' || (tok[0] != '0' && tok[0] != '1')) {
      sendErr("C needs 1 or 0");
      return;
    }
    calMode = (tok[0] == '1');
    if (calMode) { idleEnabled = false; if (idleActive) idleStop(); }
    for (uint8_t i = 0; i < NUM_CH; i++) target[i] = clampToLimit(i, target[i]);
    Serial.println(F("OK"));
  } else if (c == '?') {
    if (strtok(NULL, delim) != NULL) { sendErr("? takes no args"); return; }
    cmdState();
  } else {
    sendErr("unknown command");
  }
}

static void pollSerial(unsigned long now) {
  while (Serial.available() > 0) {
    int ch = Serial.read();
    if (ch < 0) break;
    if (ch == '\r') continue;
    if (ch == '\n') {
      if (lineOverflow) {
        sendErr("line too long");
      } else if (lineBadChar) {
        sendErr("bad character");
      } else {
        lineBuf[lineLen] = '\0';
        handleLine(lineBuf, now);
      }
      lineLen = 0;
      lineOverflow = false;
      lineBadChar = false;
      continue;
    }
    if (lineOverflow) continue;
    if ((ch < 32 || ch > 126) && ch != '\t') lineBadChar = true;
    if (lineLen >= LINE_MAX) {
      lineOverflow = true;
      continue;
    }
    lineBuf[lineLen++] = (char)ch;
  }
}

// --------------------------------------------------------------------------
void setup() {
  Serial.begin(115200);
  randomSeed(((unsigned long)analogRead(A0) << 16) ^ micros());

  pos[0] = clampToLimit(0, IDLE_EYE_CENTER[0]);
  pos[1] = clampToLimit(1, IDLE_EYE_CENTER[1]);
  pos[2] = clampToLimit(2, lidAngle(BOOT_LID_OPENNESS));
  for (uint8_t i = 0; i < NUM_CH; i++) {
    target[i] = pos[i];
    lastUs[i] = 0;
  }
  attachAll();
  pinMode(BUTTON_PIN, INPUT_PULLUP);
  pinMode(LED_BUILTIN, OUTPUT);

  unsigned long now = millis();
  lastSMs = now;
  lastTickMs = now;
  Serial.println(F(FW_BANNER));
}

void loop() {
  unsigned long now = millis();
  pollSerial(now);
  pollButton(now);
  digitalWrite(LED_BUILTIN, idleEnabled ? HIGH : LOW);

  if (idleEnabled && attached && !idleActive && now - lastSMs >= IDLE_TIMEOUT_MS) {
    idleEnter(now);
  }

  unsigned long elapsed = now - lastTickMs;
  if (elapsed >= TICK_MS) {
    lastTickMs = now;
    float dt = elapsed / 1000.0f;
    if (dt > 0.1f) dt = 0.1f;
    if (idleActive) idleUpdate(now);
    stepMotion(dt);
  }
}

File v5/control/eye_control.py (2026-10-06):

"""
Project Eye v5 - seri surucu + kalibrasyon + davranis. 3 kanal:
0 EYE_YAW, 1 EYE_PITCH, 2 LIDS (dort kapak - 2 ust + 2 alt - birlikte). v3'un
kopyasi; guvenlik kurallari ayni.

1. **Kalibrasyon**: ``eye_angles`` (kinematics.json tablosu ya da dogrusal
   formul), ``lid_angle``, ``lid_follow``, ``compute_angles``; settings.json.
2. **Baglanti** (``EyeLink``): ``EYE v5 READY`` el sikismasiyla DOGRULANAN
   port (yalnizca banner); Lunar gimbal'i (``READY``), v2 ve v3 kartlari reddedilir.
   Donanim yoksa ``sim.SimSerial``.
3. **Davranis** (``EyeController``): ``look(u, v)``, ``lids(openness)``,
   ``blink()`` (wink YOK: dort kapak tek servoda); ``update(dt)``: sakkad hiz
   siniri, kapagin pitch takibi, rastgele kirpma, bosta gezinme, keepalive.

Guvenlik: hicbir yoldan firmware limiti disinda aci gonderilmez (fw_clamp),
S acilari 2 ondalik.

    python eye_control.py            # donanimi bul, yoksa sim; demo hareketi
    python eye_control.py --sim
"""

from __future__ import annotations

import copy
import json
import math
import os
import random
import sys
import time
from typing import Callable, Iterable

import human_motion
import sim

# --------------------------------------------------------------------------
# Sabitler
# --------------------------------------------------------------------------
HERE = os.path.dirname(os.path.abspath(__file__))
V2_DIR = os.path.dirname(HERE)
SETTINGS_PATH = os.path.join(V2_DIR, "settings.json")

CHANNELS = ("EYE_YAW", "EYE_PITCH", "LIDS")
EYE_CHANNELS = ("EYE_YAW", "EYE_PITCH")
LID_CHANNELS = ("LIDS",)

BAUD = sim.BAUD
FW_BANNER = sim.FW_BANNER
LUNAR_GIMBAL_BANNER = "READY"   # lunar-tracker/firmware/pan_tilt - DOKUNMA
HANDSHAKE_TIMEOUT_S = 3.0       # Uno DTR reset + bootloader ~1.6 sn
HANDSHAKE_QUERY_AFTER_S = 2.0   # banner gelmezse (reset olmadiysa) '?' ile sor

SEND_HZ = 50.0                  # S komutu ust hizi
SEND_MIN_DELTA_DEG = 0.1        # bundan kucuk degisimi tekrar gonderme
KEEPALIVE_S = 0.5               # firmware'in 2 sn idle'ina dusmemesi icin

BLINK_S = 0.25                  # kapanma %30, kapali %20, acilma %50

# Varsayilanlar = v4 mekanik modelinin onerisi (cad/out/kinematics.json -> settings_suggestion)
DEFAULT_SETTINGS = {
    "serial_port": "auto",
    "channels": {
        "EYE_YAW": {"center": 90, "min": 65, "max": 115, "invert": True, "deg_per_unit": 25.0},
        "EYE_PITCH": {"center": 90, "min": 70, "max": 110, "invert": False, "deg_per_unit": 20.0},
        "LIDS": {"closed": 102.29, "open": 77.71, "min": 77.71, "max": 102.29, "invert": False},
    },
    "behaviour": {
        "blink_interval_s": [3, 6],
        "lid_follow_pitch": 0.0,
        "saccade_speed_deg_s": 500,
        "idle_after_s": 1.5,
        "pitch_dead": False,
        "human_motion": False,  # True: kirpma/bakinma insan istatistiklerinden (human_motion.py)   # True: pitch servosu merkezde sabit; istenen aci yalniz hesaplanir (pitch_wanted)
    },
}

# Mekanik ekibin kinematik tablolari (yoksa/okunamazsa SPEC §6 dogrusal formulu)
KINEMATICS_PATH = os.path.join(V2_DIR, "cad", "out", "kinematics.json")


class SettingsError(ValueError):
    pass


def clamp(v: float, lo: float, hi: float) -> float:
    if lo > hi:
        lo, hi = hi, lo
    return lo if v < lo else hi if v > hi else v


# --------------------------------------------------------------------------
# Ayarlar
# --------------------------------------------------------------------------
def _deep_merge(base: dict, over: dict) -> dict:
    out = copy.deepcopy(base)
    for k, v in over.items():
        if isinstance(v, dict) and isinstance(out.get(k), dict):
            out[k] = _deep_merge(out[k], v)
        else:
            out[k] = copy.deepcopy(v)
    return out


def validate_settings(s: dict) -> None:
    """Sema ve deger kontrolu; sorun varsa SettingsError (hepsini listeler)."""
    problems = []
    ch = s.get("channels", {})
    for name in CHANNELS:
        c = ch.get(name)
        if not isinstance(c, dict):
            problems.append(f"{name}: eksik")
            continue
        keys = ("center", "min", "max", "deg_per_unit") if name in EYE_CHANNELS else ("closed", "open")
        for k in keys:
            if not isinstance(c.get(k), (int, float)) or isinstance(c.get(k), bool):
                problems.append(f"{name}.{k}: sayi olmali")
            elif not 0 <= c[k] <= 180 and k != "deg_per_unit":
                problems.append(f"{name}.{k}: 0-180 disinda ({c[k]})")
        if not isinstance(c.get("invert"), bool):
            problems.append(f"{name}.invert: true/false olmali")
        nums_ok = all(isinstance(c.get(k), (int, float)) for k in keys)
        if name in EYE_CHANNELS and nums_ok:
            if not c["min"] <= c["center"] <= c["max"]:
                problems.append(f"{name}: min <= center <= max olmali")
        if name in LID_CHANNELS and ("min" in c or "max" in c):
            mm = (c.get("min"), c.get("max"))
            if not all(isinstance(x, (int, float)) and not isinstance(x, bool) for x in mm):
                problems.append(f"{name}: min ve max birlikte sayi olmali")
            elif not 0 <= mm[0] <= mm[1] <= 180:
                problems.append(f"{name}: 0 <= min <= max <= 180 olmali")
    b = s.get("behaviour", {})
    bi = b.get("blink_interval_s")
    if not (isinstance(bi, (list, tuple)) and len(bi) == 2 and 0 < bi[0] <= bi[1]):
        problems.append("behaviour.blink_interval_s: [min, max] ve 0 < min <= max olmali")
    for k in ("lid_follow_pitch", "saccade_speed_deg_s", "idle_after_s"):
        if not isinstance(b.get(k), (int, float)) or b[k] < 0:
            problems.append(f"behaviour.{k}: >= 0 sayi olmali")
    if not isinstance(b.get("human_motion"), bool):
        problems.append("behaviour.human_motion: true/false olmali")
    if not isinstance(b.get("pitch_dead"), bool):
        problems.append("behaviour.pitch_dead: true/false olmali")
    if not isinstance(s.get("serial_port"), str):
        problems.append("serial_port: metin olmali ('auto' ya da 'COM5')")
    if problems:
        raise SettingsError("; ".join(problems))


def load_settings(path: str | None = None) -> dict:
    """settings.json'u okur, eksik anahtarlari varsayilanlarla tamamlar, dogrular."""
    path = path or SETTINGS_PATH
    data = {}
    if os.path.isfile(path):
        with open(path, "r", encoding="utf-8") as f:
            data = json.load(f)
    s = _deep_merge(DEFAULT_SETTINGS, data)
    validate_settings(s)
    return s
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

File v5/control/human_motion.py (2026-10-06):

"""
Insan goz hareketi istatistikleri + tekrar etmeyen gurultu (Project Eye v5).

Kaynaklar (parametrelerin geldigi yer; dagilim BICIMLERI bizim modelleme secimimiz):

* Kirpma sikligi - Bentivoglio ve ark. 1997, "Analysis of blink rate patterns in
  normal subjects", Movement Disorders 12(6): dinlenirken ~17/dk, konusurken ~26/dk.
  Kirpmalar arasi sure saga carpik oldugu icin log-normal ile modellenir; ortalama
  60/oran olacak sekilde.
* Fiksasyon (bir noktaya bakma) suresi - Henderson 2003, "Human gaze control during
  real-world scene perception", Trends in Cognitive Sciences 7(11): sahne izlerken
  ortalama ~330 ms. Yine log-normal.
* Kirpma suresi - insan tam kirpmasi ~100-400 ms; servo kapaklarin yetisebilmesi icin
  0.20-0.32 sn araliginda.

Bakinma iki katmanli (insanlarda da boyle: buyuk sakkadla bir bolgeye gec, orada
kucuk sakkadlarla dolas):
* bolge: DONANIMIN mekanik araliginin tamamindan rastgele (v5 artifact'teki "Canli" ile
  ayni: yaw +-23/25, pitch +-17/20); 0.7-2.3 sn'de bir degisir (artifact ile ayni)
* bolge icinde: her fiksasyonda (Henderson, ort. ~330 ms) gradyan (Perlin) gurultusunden
  kucuk sapma. Kafes gradyanlari ihtiyac duyuldukca uretilir (tablo yok) -> periyot yok.
-1..1 birimi donanima baglidir: +-1 = eklemin mekanik siniri (kinematik tablo/kalibrasyon).
"""

from __future__ import annotations

import math
import random

BLINK_RATE_PER_MIN = {"rest": 17.0, "conversation": 26.0}   # Bentivoglio 1997
BLINK_IBI_SIGMA = 0.6            # log-normal sekil (saga carpik; modelleme secimi)
BLINK_IBI_RANGE_S = (0.4, 15.0)
BLINK_DURATION_S = (0.20, 0.32)

FIXATION_MEAN_S = 0.33           # Henderson 2003
FIXATION_SIGMA = 0.4
FIXATION_RANGE_S = (0.12, 1.5)

WANDER_FREQ_HZ = 0.12            # gurultu kafesinin zaman olcegi (yavas, organik kayma)
WANDER_U, WANDER_V = 23 / 25, 17 / 20   # bolge genligi: donanim araliginin payi (v5 artifact)
REGION_DWELL_S = (0.7, 2.3)      # bolge degisim araligi (v5 artifact)
MICRO_U, MICRO_V = 0.08, 0.06    # bolge icindeki kucuk sakkadlarin genligi


def _lognormal_with_mean(rng: random.Random, mean: float, sigma: float) -> float:
    """Ortalamasi `mean` olan log-normal ornek (mu = ln(mean) - sigma^2/2)."""
    return rng.lognormvariate(math.log(mean) - sigma * sigma / 2.0, sigma)


def blink_interval(rng: random.Random, context: str = "rest") -> float:
    rate = BLINK_RATE_PER_MIN.get(context, BLINK_RATE_PER_MIN["rest"])
    lo, hi = BLINK_IBI_RANGE_S
    return min(hi, max(lo, _lognormal_with_mean(rng, 60.0 / rate, BLINK_IBI_SIGMA)))


def blink_duration(rng: random.Random) -> float:
    return rng.uniform(*BLINK_DURATION_S)


def fixation_duration(rng: random.Random) -> float:
    lo, hi = FIXATION_RANGE_S
    return min(hi, max(lo, _lognormal_with_mean(rng, FIXATION_MEAN_S, FIXATION_SIGMA)))


class Noise1D:
    """Periyotsuz 1B gradyan (Perlin) gurultusu, cikti yaklasik -1..1."""

    def __init__(self, rng: random.Random):
        self._rng = rng
        self._grad: dict[int, float] = {}

    def _g(self, i: int) -> float:
        g = self._grad.get(i)
        if g is None:
            g = self._grad[i] = self._rng.uniform(-1.0, 1.0)
        return g

    def __call__(self, x: float) -> float:
        i = math.floor(x)
        f = x - i
        fade = f * f * f * (f * (f * 6 - 15) + 10)
        a, b = self._g(i) * f, self._g(i + 1) * (f - 1)
        return 2.0 * (a + (b - a) * fade)     # 1B Perlin ~ +-0.5 -> +-1


class GazeWander:
    """Insan benzeri bakinma: bolge (tam donanim araligi) + bolge icinde fiksasyon -> kucuk sakkad."""

    def __init__(self, rng: random.Random):
        self.rng = rng
        self._nu, self._nv = Noise1D(rng), Noise1D(rng)
        self._phase = rng.uniform(0, 1000)
        self._next_fix = -1.0
        self._next_region = -1.0
        self.region = (0.0, 0.0)
        self.target = (0.0, 0.0)

    def step(self, now: float):
        if now >= self._next_region:
            self.region = (self.rng.uniform(-WANDER_U, WANDER_U), self.rng.uniform(-WANDER_V, WANDER_V))
            self._next_region = now + self.rng.uniform(*REGION_DWELL_S)
            self._next_fix = now
        if now >= self._next_fix:
            x = self._phase + now * WANDER_FREQ_HZ * 8
            u = self.region[0] + MICRO_U * self._nu(x)
            v = self.region[1] + MICRO_V * self._nv(x + 57.3)
            self.target = (max(-1.0, min(1.0, u)), max(-1.0, min(1.0, v)))
            self._next_fix = now + fixation_duration(self.rng)
        return self.target

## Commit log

2026-10-02 Project Eye v1-v5: animatronic eye mechanism (CAD as code, firmware, control, viewer)
    [assembly.step, back_frame.step, back_frame.stl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]
2026-10-03 README: honest v5 status; firmware: replace raw NUL byte with '\0' escape
    The C-command check contained a literal NUL byte inside a char constant.
    GCC accepts it (value 0) but git and grep treat the file as binary and
    editors may display it as a space. Behavior is unchanged.
    Claude-Session: https://claude.ai/code/session_01MvUrPqLZnEmv2FqPkFYBkM
    [project_eye_v5.ino]
2026-10-06 v5 face_follow: remove on-screen eye schematic overlay
2026-10-06 v5 tracker: IDLE/CANLI/NOTR/TRACKING mode buttons; panel tool entry
2026-10-06 v5: pitch_dead - pitch servo held at center, wanted angle only displayed
2026-10-06 v5 tracker: show computed pitch in telemetry line
2026-10-06 v5: human-statistics blink/fixation model + non-periodic gaze wander
    Blink rate from Bentivoglio et al. 1997 (rest ~17/min, conversation ~26/min),
    fixation duration from Henderson 2003 (~330 ms), gaze points from lazily
    generated gradient noise so the pattern has no period.
    [eye_control.py, face_follow.py, human_motion.py]
2026-10-06 v5 tracker: bring back top-right eye schematic
2026-10-06 v5: gaze range bound to calibrated hardware limits; wander covers full range
    Table mapping now scales so u/v = +-1 reaches the calibrated servo min/max
    (yaw 45-111) instead of stopping at the CAD table's +-25 deg. Idle wander
    picks regions across the whole hardware range (as in the v5 viewer) with
    human-statistics fixations inside each region.
    [eye_control.py, human_motion.py]
2026-10-06 v5 settings: yaw invert false (direction reversed on hardware)
2026-10-06 v5 tracker: add TRACKING CANSIZ (plain tracking) button; fit eye schematic top-right
2026-10-06 v5: stand HUD for tracker; D2 button cycles tracker modes
    - hud.py: header with human-readable status, HUD face brackets with confidence,
    gaze reticle, restyled eye schematic, small pill mode buttons at bottom,
    debug line behind 'i'
    - firmware: while the PC is driving, a D2 press prints BTN instead of toggling
    idle; tracker advances to the next mode (sim mirrors it)
2026-10-06 v5 tracker: LIVE / T LIVE / T / NEUTRAL labels + MANUAL mode (drag gaze, wheel lids, arrows)
2026-10-06 v5 tracker: fix mouse wheel on OpenCV 5 (no getMouseWheelDelta); drop manual hint; KAPAK -> LID
    [face_follow.py]
2026-10-06 v5 tracker: hardware health on the eye schematic (sim / connection lost / no response / board reset)
    Heartbeat '?' every 0.5 s; schematic greys out with a warning when the board
    stops answering, the port dies or the board reboots (brown-out).
    [eye_control.py, face_follow.py, hud.py]
2026-10-06 v5 tracker: freeze eye schematic while the board is not answering
2026-10-06 v5 tracker: faults recover on their own (background reconnect)
    Lost port or no hardware: a background scan finds the board again when the
    port list changes (cable plugged) or every 10 s; long silence closes and
    reopens the port. Scanning is not repeated while ports are unchanged so other
    boards on USB are not reset continuously.
    [face_follow.py]
2026-10-06 v5 tracker: hang watchdog dumps all thread stacks to face_follow_hang.log
2026-10-24 README: pitch is disabled; face tracking ran on v5 hardware (yaw only)
2026-10-25 v5: serial I/O on its own thread in the tracker
    The FTDI driver can block forever inside write/read/close when USB or power
    glitches (process became unkillable and the window froze). The tracker now
    queues writes and collects reads on a worker thread and closes ports off the
    main thread; a stuck driver only shows as NO RESPONSE / CONNECTION LOST.
